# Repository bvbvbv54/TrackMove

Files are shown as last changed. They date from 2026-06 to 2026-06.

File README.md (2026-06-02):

# Autonomous Industrial Line-Following Robot

A compact, PCB-integrated autonomous line-following robot built on the Arduino Nano platform. This project demonstrates embedded systems design encompassing custom PCB development, sensor integration, motor control, and real-time firmware development.

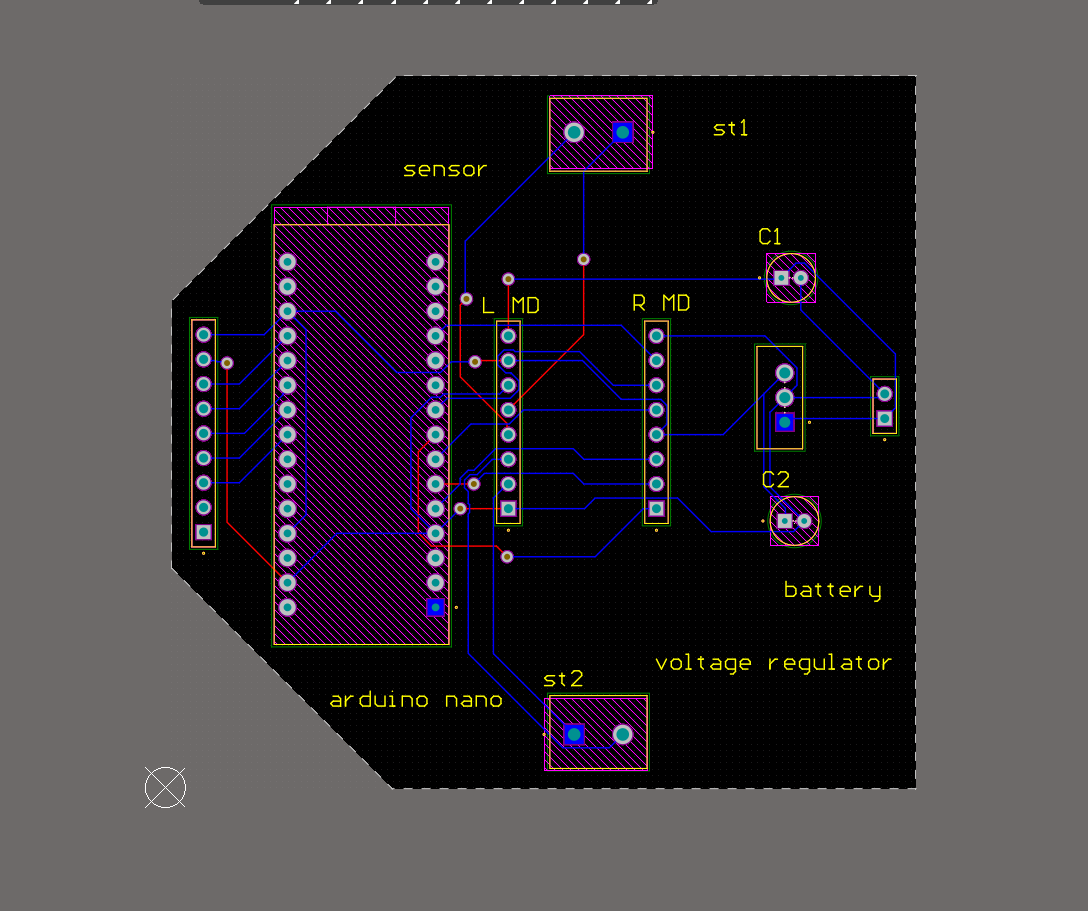
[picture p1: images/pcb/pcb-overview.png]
PCB Layout


---

## Project Overview

This repository documents the complete design, development, and validation of an autonomous line-following robot intended for industrial and academic applications. The system uses infrared sensor arrays to detect and track a contrasting line on a flat surface, executing proportional-derivative (PD) control to maintain trajectory with minimal oscillation.

The robot is built around a custom-designed two-layer PCB that integrates power regulation, motor driving, sensor interfacing, and microcontroller hosting into a single compact board.

---

## Engineering Objectives

| Objective | Description |
|---|---|
| **Sensor Integration** | Interface a 5-channel IR sensor array for real-time line position detection |
| **Motor Control** | Implement bidirectional DC motor control with PWM-based speed regulation |
| **Power Management** | Design a regulated power distribution system from battery source to all subsystems |
| **PCB Design** | Develop a custom two-layer PCB with proper power integrity and signal routing |
| **Embedded Firmware** | Write efficient Arduino-based firmware implementing PD line-following control |
| **System Integration** | Combine all subsystems into a functional, testable autonomous platform |

---

## Key Features

- **5-Channel IR Sensor Array** — TCRT5000-based reflective sensors for robust line detection across varying surface conditions
- **Dual H-Bridge Motor Driver** — TB6612FNG driver for independent left/right motor control with PWM speed regulation
- **Regulated Power Architecture** — LM7805-based 5V regulation with bulk and bypass capacitors for noise suppression
- **Custom PCB Design** — Two-layer board designed in Altium Designer with optimized component placement and routing
- **PD Control Algorithm** — Proportional-derivative control for smooth trajectory tracking with minimal overshoot
- **Compact Form Factor** — Single-board design reducing wiring complexity and improving reliability

---

## System Architecture

```mermaid
graph TB
    subgraph Power["Power Subsystem"]
        BAT[Battery<br/>7.4V-9V]
        REG[LM7805<br/>5V Regulator]
        C1[100nF<br/>Bypass Cap]
        C2[10uF<br/>Bulk Cap]
    end

    subgraph MCU["Microcontroller"]
        NANO[Arduino Nano<br/>ATmega328P]
    end

    subgraph Sensors["Sensor Subsystem"]
        IR1[TCRT5000 Ch1]
        IR2[TCRT5000 Ch2]
        IR3[TCRT5000 Ch3]
        IR4[TCRT5000 Ch4]
        IR5[TCRT5000 Ch5]
    end

    subgraph Driver["Motor Driver"]
        TB66[TB6612FNG<br/>Dual H-Bridge]
    end

    subgraph Actuators["Actuators"]
        ML[Left DC Motor<br/>N20 Gear Motor]
        MR[Right DC Motor<br/>N20 Gear Motor]
    end

    BAT --> REG
    REG --> C1
    REG --> C2
    REG -->|+5V| NANO
    REG -->|+5V| TB66
    REG -->|+5V| IR1
    REG -->|+5V| IR2
    REG -->|+5V| IR3
    REG -->|+5V| IR4
    REG -->|+5V| IR5

    NANO -->|AIN1 AIN2 PWMA| TB66
    NANO -->|BIN1 BIN2 PWMB| TB66

    IR1 -->|A0| NANO
    IR2 -->|A1| NANO
    IR3 -->|A2| NANO
    IR4 -->|A3| NANO
    IR5 -->|A4| NANO

    TB66 -->|Motor A| ML
    TB66 -->|Motor B| MR
```

---

## Hardware Components

| Component | Part Number | Quantity | Function |
|---|---|---|---|
| Arduino Nano | ATmega328P | 1 | Main microcontroller, PD computation, I/O control |
| TB6612FNG Motor Driver | TB6612FNG | 1 | Dual H-Bridge motor driver, PWM speed control |
| TCRT5000 IR Sensor | TCRT5000 | 5 | Reflective IR sensor for line detection |
| N20 DC Gear Motor | N20 | 2 | Compact gear motors for wheel actuation |
| LM7805 Voltage Regulator | LM7805CFG | 1 | 5V linear voltage regulation from battery |
| Electrolytic Capacitor | ECEA1HKS4R7 | 1 | 10uF bulk capacitance on regulator output |
| Ceramic Capacitor | 100nF | 1 | Bypass capacitor on regulator input |
| SSQ-109-06-G-S Header | Samtec SSQ | 1 | 9-pin sensor interface connector |
| SSQ-108-X-X-S Header | Samtec SSQ | 2 | 8-pin motor driver interface connectors |
| SSQ-102-03-F-S Header | Samtec SSQ | 1 | 3-pin battery input connector |

---

## PCB Design

The custom PCB was designed in Altium Designer as a two-layer board with the following considerations:

- **Component Placement**: Arduino Nano centrally located for short trace runs to peripherals. Motor driver positioned between Nano and motor connectors. Sensor header along the front edge for optimal sensor positioning.
- **Power Distribution**: Dedicated power traces routed with adequate width for motor current. Separate +5V regulation section with proper input/output capacitance.
- **Signal Routing**: Analog sensor traces routed away from power lines to minimize noise coupling. Motor driver control signals kept short and direct.
- **Board Outline**: Custom polygon shape optimized for robot chassis mounting with mounting holes at corners.

See [PCB Design Documentation](docs/pcb-design.md) for detailed analysis.

---

## Embedded Control

The firmware implements a PD (Proportional-Derivative) control algorithm:

1. **Sensor Acquisition** — Reads 5 analog IR sensor values at defined intervals
2. **Position Calculation** — Computes weighted average of sensor readings to determine line position
3. **Error Computation** — Calculates error term (deviation from center position)
4. **PD Control** — Applies proportional and derivative terms to compute motor correction
5. **Motor Command** — Translates correction value into differential PWM signals for left/right motors

```
Motor_Output = Kp * error + Kd * (error - prev_error)
Left_Motor  = Base_Speed + Motor_Output
Right_Motor = Base_Speed - Motor_Output
```

---

## Testing and Validation

| Test Category | Description | Status |
|---|---|---|
| Sensor Calibration | Individual IR sensor threshold verification across line/surface | Verified |
| Motor Driver | PWM response validation, direction control, stall current measurement | Verified |
| Power Integrity | Regulated voltage stability under varying load conditions | Verified |
| PD Tuning | Kp and Kd parameter optimization for smooth line tracking | Tuned |
| Integration Testing | Full system autonomous line-following on standard test track | Validated |

See [Testing & Validation Documentation](docs/testing-and-validation.md) for detailed procedures.

---

## Project Structure

```
Autonomous-Line-Following-Robot/
├── README.md                          # This file
├── LICENSE                            # MIT License
├── docs/
│   ├── architecture.md                # System architecture deep-dive
│   ├── hardware-design.md             # Hardware design documentation
│   ├── pcb-design.md                  # PCB design methodology and decisions
│   └── testing-and-validation.md      # Testing procedures and results
├── images/
│   ├── robot_photos/                  # Assembled robot photographs
│   ├── schematics/                    # Schematic screenshots
│   └── pcb/                           # PCB layout screenshots
├── firmware/                          # Arduino firmware source code
└── hardware/
    ├── schematics/                    # Altium schematic files (.schdoc)
    ├── pcb/                           # Altium PCB layout files (.PcbDoc)
    └── track-move.PrjPcb              # Altium project file
```

---

## Lessons Learned

1. **Power Supply Decoupling** — Adequate bypass capacitance near the motor driver IC is critical to prevent voltage dips during motor startup transients.
2. **Sensor Mounting Height** — TCRT5000 sensors are sensitive to distance from the reflecting surface; consistent mounting height (5-10mm) is essential for reliable detection.
3. **PWM Frequency Selection** — Motor driver PWM frequency must be chosen to avoid audible noise while maintaining sufficient torque at low speeds.
4. **Ground Plane Design** — A continuous ground plane on the bottom layer significantly reduces noise in analog sensor readings.
5. **Connector Selection** — Pin header connectors provide reliable, serviceable connections for prototyping; consider screw terminals for production.

---

## Future Improvements

- **PID Control** — Upgrade from PD to full PID control for improved steady-state error correction
- **Speed Optimization** — Implement adaptive speed control (slow on curves, fast on straights)
- **Wireless Telemetry** — Add Bluetooth module for real-time parameter tuning and data logging
- **Multi-Line Detection** — Extend sensor array to detect intersections, markers, and track features
- **PCB Revision** — Add dedicated motor driver IC footprint (TB6612FNG) directly on board instead of header-based module
- **Battery Monitoring** — Implement voltage divider circuit for battery level monitoring via ADC

---

## License

This project is licensed under the MIT License. See [LICENSE](LICENSE) for details.

---

## Author

*Academic Embedded Systems Project*

For questions or collaboration inquiries, please open an issue on this repository.

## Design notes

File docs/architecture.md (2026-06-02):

# System Architecture

This document describes the complete system architecture of the Autonomous Industrial Line-Following Robot, detailing each subsystem, signal flow, and control methodology.

---

## System Overview

The robot operates as a closed-loop control system with the following fundamental loop:

```
Sensors → Microcontroller → Motor Driver → Motors → Robot Motion → Sensors
```

This continuous feedback loop enables the robot to track a line autonomously by constantly correcting its trajectory based on sensor readings.

---

## Subsystem Architecture

### 1. Power Subsystem

**Purpose**: Convert unregulated battery voltage to a stable 5V supply for all digital and analog components.

**Components**:
- Battery input connector (SSQ-102-03-F-S): Accepts 7.4V–9V DC input
- LM7805CFG linear voltage regulator: Steps down to regulated 5V
- Input capacitor C1 (100nF ceramic): High-frequency noise filtering
- Output capacitor C2 (10uF electrolytic): Bulk energy storage and transient response

**Power Flow**:
```
Battery (7.4-9V) → [C1: 100nF] → LM7805 IN → LM7805 OUT → [C2: 10µF] → +5V Rail
                                                                      ↓
                                                            Arduino Nano
                                                            TB6612FNG (VCC)
                                                            TCRT5000 Array
```

**Design Considerations**:
- The LM7805 requires a minimum 2V dropout voltage, so input must be ≥7V for reliable 5V output
- Maximum output current is 1A (limited by LM7805 and thermal dissipation)
- Motor driver receives battery voltage directly (VCC pin) for motor power, with 5V for logic
- Bypass capacitors placed as close as possible to regulator pins

---

### 2. Microcontroller Subsystem

**Purpose**: Execute PD control algorithm, read sensors, and generate motor control signals.

**Component**: Arduino Nano (ATmega328P)

**Pin Assignment**:

| Pin | Function | Direction | Connection |
|-----|---|---|---|
| A0 | Analog Input | Input | TCRT5000 Channel 1 (leftmost) |
| A1 | Analog Input | Input | TCRT5000 Channel 2 |
| A2 | Analog Input | Input | TCRT5000 Channel 3 (center) |
| A3 | Analog Input | Input | TCRT5000 Channel 4 |
| A4 | Analog Input | Input | TCRT5000 Channel 5 (rightmost) |
| D2 | Digital Output | Output | TB6612FNG AIN1 (motor A direction) |
| D3 | Digital Output | Output | TB6612FNG AIN2 (motor A direction) |
| D5 | PWM Output | Output | TB6612FNG PWMA (motor A speed) |
| D4 | Digital Output | Output | TB6612FNG BIN1 (motor B direction) |
| D7 | Digital Output | Output | TB6612FNG BIN2 (motor B direction) |
| D6 | PWM Output | Output | TB6612FNG PWMB (motor B speed) |
| +5V | Power Input | Power | Regulated 5V from LM7805 |
| GND | Ground | Power | Common ground |

**Processing Loop**:
1. Read all 5 analog sensor channels
2. Calculate weighted line position
3. Compute error from center
4. Apply PD control law
5. Update PWM outputs
6. Repeat at fixed interval (10ms typical)

---

### 3. Sensor Subsystem

**Purpose**: Detect the line position relative to the robot center.

**Component**: 5x TCRT5000 Reflective IR Sensor Modules

**Operating Principle**:
- Each TCRT5000 contains an IR emitter and phototransistor
- IR light reflects off light surfaces (high reading) and is absorbed by dark surfaces (low reading)
- The sensor array outputs analog voltages proportional to reflectivity
- A dark line on a light surface produces low readings on sensors over the line

**Sensor Array Configuration**:
```
Position:   [S1]   [S2]   [S3]   [S4]   [S5]
Arduino Pin: A0     A1     A2     A3     A4
Location:    Left   Left-  Center Right- Right
                      Mid          Mid
```

**Weighted Position Calculation**:
```c
position = (S1 * 1 + S2 * 2 + S3 * 3 + S4 * 4 + S5 * 5) / (S1 + S2 + S3 + S4 + S5)
```

This produces a value from 1.0 (line at far left) to 5.0 (line at far right), with 3.0 being centered.

**Interface**: Direct analog connection to Arduino Nano ADC pins. No multiplexing required.

---

### 4. Motor Driver Subsystem

**Purpose**: Translate low-power microcontroller signals into high-current motor drive.

**Component**: TB6612FNG Dual H-Bridge Motor Driver

**Key Specifications**:
- Supply voltage: 2.5V–13.5V (motor), 2.5V–5.5V (logic)
- Output current: 1.2A continuous per channel, 3.2A peak
- Low saturation voltage (MOSFET-based H-bridge)
- Built-in thermal shutdown

**Control Interface**:

| Arduino Pin | TB6612FNG Pin | Function |
|---|---|---|
| D2 | AIN1 | Motor A direction bit 1 |
| D3 | AIN2 | Motor A direction bit 2 |
| D5 | PWMA | Motor A speed (PWM) |
| D4 | BIN1 | Motor B direction bit 1 |
| D7 | BIN2 | Motor B direction bit 2 |
| D6 | PWMB | Motor B speed (PWM) |

**Direction Control Truth Table**:

| AIN1 | AIN2 | Motor A Direction |
|---|---|---|
| HIGH | LOW | Forward |
| LOW | HIGH | Reverse |
| LOW | LOW | Brake (short) |
| HIGH | HIGH | Brake (short) |

**Motor Power Path**:
```
Battery VCC → TB6612FNG VM pin → H-Bridge → Motor terminals
5V Rail     → TB6612FNG VCC pin → Logic supply
```

> **Note**: The motor driver module is connected via SSQ-108-X-X-S pin headers, allowing easy replacement or servicing.

---

### 5. Actuator Subsystem

**Purpose**: Convert electrical drive signals into mechanical motion.

**Components**: 2x N20 DC Gear Motors

**Specifications** (typical N20):
- Operating voltage: 3V–6V
- No-load speed: ~200 RPM at 6V
- Stall torque: ~15 g·cm
- Gear ratio: ~1:100

**Mechanical Configuration**:
- Differential drive: two independently controlled wheels
- Left motor connected to TB6612FNG Channel A
- Right motor connected to TB6612FNG Channel B
- Steering achieved through speed differential (no steering mechanism)

**Turning Dynamics**:
| Left Speed | Right Speed | Motion |
|---|---|---|
| Equal | Equal | Straight forward |
| Lower | Higher | Turn left |
| Higher | Lower | Turn right |
| Forward | Reverse | Spin in place |

---

## Signal Flow Diagram

```mermaid
sequenceDiagram
    participant Battery
    participant Regulator as LM7805
    participant Nano as Arduino Nano
    participant Sensors as TCRT5000 Array
    participant Driver as TB6612FNG
    participant Motors as N20 Motors

    Battery->>Regulator: 7.4-9V DC
    Regulator->>Nano: +5V regulated
    Regulator->>Sensors: +5V regulated
    Regulator->>Driver: +5V logic
    Battery->>Driver: VCC (motor power)

    loop Control Loop (10ms)
        Sensors->>Nano: Analog readings (A0-A4)
        Note over Nano: Calculate position
        Note over Nano: Compute PD error
        Note over Nano: Generate PWM
        Nano->>Driver: AIN1, AIN2, PWMA
        Nano->>Driver: BIN1, BIN2, PWMB
        Driver->>Motors: H-Bridge output
        Motors->>Sensors: Physical motion changes line position
    end
```

---

## Timing Analysis

| Operation | Duration | Frequency |
|---|---|---|
| ADC Conversion (5 channels) | ~100 µs | — |
| PD Calculation | ~20 µs | — |
| PWM Update | ~10 µs | — |
| **Total Loop Time** | **~130 µs** | **~7.7 kHz theoretical** |
| Practical Loop Time | ~10 ms | ~100 Hz (with delay) |

> The firmware typically operates at 100 Hz (10ms loop), which is well within the mechanical response time of the N20 gear motors.

---

## Grounding Strategy

- **Common Ground**: All subsystems share a single ground reference connected through the PCB ground plane
- **Star Grounding**: Power ground (motor return) and signal ground (sensor/ADC) are connected at a single point near the voltage regulator
- **Ground Plane**: Bottom PCB layer uses a continuous ground pour to minimize impedance and noise coupling

---

## Failure Modes and Protections

| Failure Mode | Cause | Protection |
|---|---|---|
| Motor stall current | Mechanical jam | TB6612FNG thermal shutdown at ~150°C |
| Voltage spike | Motor back-EMF | TVS diode (if present) or input capacitor absorption |
| Sensor noise | Electrical interference | 100nF bypass caps on sensor supply, software filtering |
| Brown-out | Battery depletion | ATmega328P internal brown-out detection at 2.7V |
| Overheating | Sustained high current | LM7805 thermal shutdown at ~175°C |

---

## Design Assumptions

> The following items are inferred from the schematic and PCB layout. Exact values should be verified against the Altium project files.

1. Motor driver module is assumed to be TB6612FNG based on pin count and application context
2. IR sensors are assumed to be TCRT5000 modules based on the 5-channel configuration and analog output
3. N20 gear motors are assumed based on connector labels and application requirements
4. PWM frequency is assumed to be default Arduino configuration (~490 Hz or ~980 Hz depending on pin)
5. Control loop timing is firmware-dependent and subject to implementation details

---

## References

1. Arduino Nano Datasheet — ATmega328P
2. TB6612FNG Dual H-Bridge Motor Driver Datasheet
3. TCRT5000 Reflective Optical Sensor Datasheet
4. LM7805 Linear Voltage Regulator Datasheet
5. N20 DC Gear Motor Specifications

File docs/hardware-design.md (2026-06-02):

# Hardware Design Documentation

This document provides a detailed analysis of the hardware design for the Autonomous Industrial Line-Following Robot, covering schematic design decisions, component selection rationale, and circuit analysis.

---

## Design Overview

The hardware consists of a single custom PCB that integrates all subsystems: power regulation, microcontroller hosting, motor driving, and sensor interfacing. The design was developed in Altium Designer using a two-layer PCB stackup.

---

## Schematic Analysis

The schematic is organized into five distinct functional blocks:

### Block 1: Power Supply

Schematic Overview

**Circuit Description**:

```
Battery+ ──┬── C1 (100nF) ──┬── LM7805 IN
           │                │
           │            LM7805 GND
           │                │
           │            LM7805 OUT ──┬── C2 (10µF) ──┬── +5V Rail
           │                        │               │
           │                        │           [To All Subsystems]
           │                        │
Battery- ──┴────────────────────────┴── GND
```

**Component Selection Rationale**:

| Component | Selected | Alternative Considered | Reason for Selection |
|---|---|---|---|
| Voltage Regulator | LM7805CFG | LM1117-5.0, LM2596 | Simple, reliable, sufficient current for this application |
| Input Capacitor | 100nF ceramic | 10µF electrolytic | Ceramic preferred for high-frequency noise; bulk cap on output |
| Output Capacitor | 10µF electrolytic | 100µF electrolytic | Provides adequate transient response for motor current steps |

**Power Budget Analysis**:

| Subsystem | Nominal Current | Peak Current |
|---|---|---|
| Arduino Nano | ~45 mA | ~50 mA |
| TB6612FNG Logic | ~10 mA | ~20 mA |
| TCRT5000 Array (5x) | ~50 mA | ~75 mA |
| **Total 5V Rail** | **~105 mA** | **~145 mA** |
| Motors (2x N20) | ~150 mA | ~400 mA (stall) |

> The LM7805 comfortably handles the 5V rail requirements. Motor current is supplied directly from battery through the TB6612FNG, bypassing the regulator.

---

### Block 2: Microcontroller

**Component**: Arduino Nano (ATmega328P-based module)

The Arduino Nano serves as the central processing unit, executing the control algorithm and managing all I/O operations.

**Key Connections**:

| Nano Pin | Net Name | Destination | Signal Type |
|---|---|---|---|
| A0 | SENSOR_CH1 | TCRT5000 Array | Analog Input |
| A1 | SENSOR_CH2 | TCRT5000 Array | Analog Input |
| A2 | SENSOR_CH3 | TCRT5000 Array | Analog Input |
| A3 | SENSOR_CH4 | TCRT5000 Array | Analog Input |
| A4 | SENSOR_CH5 | TCRT5000 Array | Analog Input |
| D2 | AIN1 | TB6612FNG | Digital Output |
| D3 | AIN2 | TB6612FNG | Digital Output |
| D4 | BIN1 | TB6612FNG | Digital Output |
| D5 | PWMA | TB6612FNG | PWM Output |
| D6 | PWMB | TB6612FNG | PWM Output |
| D7 | BIN2 | TB6612FNG | Digital Output |
| 5V | VCC | LM7805 Output | Power |
| GND | GND | Ground Plane | Power |

**Design Notes**:
- Nano is mounted via pin headers for easy removal during programming
- Reset pin is accessible via a dedicated header (st2) for in-circuit reset
- ADC pins A0–A4 are dedicated to sensor inputs to avoid multiplexing complexity
- PWM pins D5 and D6 are used for motor speed control (Timer0 and Timer0 channels)

> **Assumption**: The Arduino Nano is a pre-built module with onboard USB-to-serial converter (CH340 or FTDI). The exact variant should be verified against the physical board.

---

### Block 3: IR Sensor Array

**Component**: 5x TCRT5000 Reflective Optical Sensors

**Circuit Topology**:

```
+5V ──┬── [TCRT5000 Sensor 1] ──┬── AO1 ── A0 (Nano)
      │   [TCRT5000 Sensor 2] ──┼── AO2 ── A1 (Nano)
      │   [TCRT5000 Sensor 3] ──┼── AO3 ── A2 (Nano)
      │   [TCRT5000 Sensor 4] ──┼── AO4 ── A3 (Nano)
      │   [TCRT5000 Sensor 5] ──┴── AO5 ── A4 (Nano)
      │
GND ──┴── [All Sensors Common GND]
```

**Connector**: SSQ-109-06-G-S (9-pin header)
- 5 analog output pins
- 2 power pins (+5V, GND)
- 2 additional pins (likely reserved or unused)

**Sensor Characteristics**:

| Parameter | Value | Notes |
|---|---|---|
| Emitter wavelength | 950 nm | IR LED |
| Detection distance | 1–25 mm | Optimal at 5–10 mm |
| Output type | Analog voltage | Proportional to reflectivity |
| Supply current | ~10 mA per sensor | |
| Output voltage range | 0V – 3.3V | Dependent on surface reflectivity |

**Signal Conditioning**:
- No external signal conditioning is used; the TCRT5000 modules include onboard amplification
- The analog outputs connect directly to the Arduino ADC (0–5V range)
- Sensor height above the surface is a critical installation parameter

---

### Block 4: Motor Driver

**Component**: TB6612FNG Dual H-Bridge Motor Driver

The motor driver module interfaces with the PCB via two SSQ-108-X-X-S (8-pin) connectors labeled "L MD" (Left Motor Driver) and "R MD" (Right Motor Driver).

**Pin Mapping**:

```
L MD Connector (Left Motor):
  Pin 1: +VCC (Battery voltage, motor supply)
  Pin 2: +5V (Logic supply)
  Pin 3: GND
  Pin 4: GND
  Pin 5: AIN2 ← Nano D3
  Pin 6: AIN1 ← Nano D2
  Pin 7: AO2  → Left Motor Terminal 2
  Pin 8: AO1  → Left Motor Terminal 1

R MD Connector (Right Motor):
  Pin 1: PWMA ← Nano D5
  Pin 2: AIN2
  Pin 3: BIN1 ← Nano D4
  Pin 4: AIN1
  Pin 5: BIN2 ← Nano D7
  Pin 6: PWMB ← Nano D6
  Pin 7: +5V
  Pin 8: GND
```

**Motor Terminal Connections**:
- Left motor: Connected via st1 connector (labeled "Motors Entry" in schematic)
- Right motor: Connected via st2 connector

**Driver Operating Modes**:

| Mode | AIN1 | AIN2 | PWMA | Result |
|---|---|---|---|---|
| Forward | 1 | 0 | PWM duty | Motor spins forward at PWM speed |
| Reverse | 0 | 1 | PWM duty | Motor spins reverse at PWM speed |
| Brake | 1 | 1 | X | Motor brakes (short circuit) |
| Coast | 0 | 0 | X | Motor coasts (high impedance) |

---

### Block 5: Motor Entry (Output Connectors)

**Components**:
- st1: Motor output connector for left motor
- st2: Motor output connector for right motor

These are simple 2-pin screw terminal or pin header connections that route the TB6612FNG H-bridge outputs to the physical motors.

---

## Interconnections Summary

```mermaid
graph LR
    subgraph Battery
        BATT[7.4V Battery]
    end

    subgraph Power
        REG[LM7805<br/>5V Reg]
        C1[C1 100nF]
        C2[C2 10uF]
    end

    subgraph MCU
        NANO[Arduino Nano]
    end

    subgraph Sensors
        SENS[TCRT5000<br/>5-Ch Array]
    end

    subgraph Driver
        TB66[TB6612FNG<br/>Dual H-Bridge]
    end

    subgraph Motors
        ML[Left Motor]
        MR[Right Motor]
    end

    BATT -->|VCC| REG
    BATT -->|VCC| TB66
    REG -->|+5V| NANO
    REG -->|+5V| SENS
    REG -->|+5V| TB66

    SENS -->|A0-A4| NANO
    NANO -->|D2,D3,D5| TB66
    NANO -->|D4,D6,D7| TB66

    TB66 -->|AO1,AO2| ML
    TB66 -->|BO1,BO2| MR
```

---

## Bill of Materials (Inferred)

| Reference | Component | Package | Qty | Notes |
|---|---|---|-----|---|
| U1 | Arduino Nano | Module | 1 | ATmega328P, USB interface |
| U2 | TB6612FNG Module | Module | 1 | Dual H-bridge, connected via headers |
| U3 | LM7805CFG | TO-220 | 1 | 5V linear regulator |
| IR1–IR5 | TCRT5000 Sensor | Module | 5 | Reflective IR sensor modules |
| M1, M2 | N20 DC Gear Motor | — | 2 | With wheels |
| C1 | Ceramic Capacitor 100nF | Through-hole | 1 | Regulator input bypass |
| C2 | Electrolytic Capacitor 10µF | Radial | 1 | Regulator output bulk |
| J1 | SSQ-102-03-F-S | Header | 1 | Battery input connector |
| J2 | SSQ-109-06-G-S | Header | 1 | Sensor array connector |
| J3, J4 | SSQ-108-X-X-S | Header | 2 | Motor driver connectors |
| J5, J6 | Motor Output | Connector | 2 | Motor terminal connections |

---

## Design Trade-offs

### Why Linear Regulator (LM7805) Over Switching?

| Factor | LM7805 (Linear) | LM2596 (Switching) |
|---|---|---|
| Efficiency | ~50% (at 9V input) | ~85% |
| Complexity | Very simple | Requires inductor, diode |
| Noise | Very low | Higher (switching ripple) |
| Cost | Very low | Low |
| Board space | Small | Larger (external components) |

**Decision**: The linear regulator was selected for simplicity and low noise, which benefits the analog sensor readings. The efficiency penalty is acceptable given the moderate current requirements of the 5V rail.

### Why Header-Based Module Instead of Soldered IC?

The TB6612FNG is connected via pin headers rather than soldered directly to the PCB. This design choice:
- Simplifies prototyping and debugging
- Allows module replacement if damaged
- Reduces PCB complexity (no fine-pitch soldering)
- Increases overall height but acceptable for this application

---

## Assumptions and Limitations

1. **Component Values**: Capacitor values (C1=100nF, C2=10µF) are inferred from the schematic and standard practice. Exact values should be verified against the Altium schematic.

2. **Motor Driver**: The specific motor driver IC (TB6612FNG) is inferred from the application context and pin configuration. Alternative dual H-bridge drivers may be compatible.

3. **Sensor Type**: TCRT5000 is assumed based on the 5-channel analog configuration. Other reflective IR sensor modules may be compatible.

4. **Thermal Performance**: No heatsink is shown for the LM7805. At 9V input and 150mA load, power dissipation is approximately 600mW, which is within the TO-220 package capability but may require thermal consideration for sustained operation.

5. **EMI Considerations**: The schematic does not show explicit EMI filtering components beyond the bypass capacitors. For production use, additional ferrite beads or common-mode chokes may be beneficial.

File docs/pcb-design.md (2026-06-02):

# PCB Design Documentation

This document covers the PCB design methodology, layout decisions, routing strategy, and verification process for the Autonomous Industrial Line-Following Robot custom circuit board.

---

## Design Environment

| Parameter | Value |
|---|---|
| EDA Tool | Altium Designer |
| Board Type | Two-layer (双面板) |
| Layer Stack | Top Layer (components + routing), Bottom Layer (routing + ground pour) |
| Design File | `PCB1.PcbDoc` |
| Project File | `track-move.PrjPcb` |
| Schematic File | `trackmove-schem.schdoc` |

---

## PCB Layout Analysis

PCB Layout

### Board Geometry

The PCB features a custom polygon outline, not a standard rectangular shape. The board outline is optimized to:

- Accommodate the Arduino Nano form factor centrally
- Provide mounting points for the N20 gear motors at the rear edge
- Allow sensor array positioning along the front edge
- Fit within a compact robot chassis envelope

**Estimated Dimensions**: Approximately 80mm × 70mm (inferred from component scaling).

### Component Placement Strategy

The layout follows a logical signal flow from left to right:

```
[Front Edge]                    [Center]              [Rear Edge]
IR Sensors ──────────→ Arduino Nano ──────────→ Motor Driver
(SSQ-109-06)           (Pin Headers)            (SSQ-108-X-X-S)
                                                        ↓
                                              Battery + Regulator
                                              Motor Connectors
```

**Placement Decisions**:

| Component | Placement | Rationale |
|---|---|---|
| Arduino Nano | Center-left | Central position minimizes trace length to both sensors and motor driver |
| Sensor Header (J2) | Front-left edge | Direct alignment with sensor array for clean analog signal routing |
| Motor Driver Headers (J3, J4) | Center-right | Short path to motor output connectors |
| Voltage Regulator (U3) | Rear-right | Isolated from sensitive analog circuits; close to battery input |
| Battery Connector (J1) | Rear-right | Direct connection to regulator and motor driver power pins |
| Motor Connectors (st1, st2) | Rear edge | Close proximity to motor driver outputs |
| Capacitors (C1, C2) | Adjacent to regulator | Minimize loop area for effective decoupling |
| Mounting Holes | Corners | Mechanical stability and chassis attachment |

---

## Routing Considerations

### Layer Assignment

| Layer | Usage |
|---|---|
| Top Layer (Red) | Component placement, primary signal routing, power traces |
| Bottom Layer (Blue) | Secondary signal routing, ground pour |
| Top Overlay (Yellow) | Silkscreen labels, component outlines, text annotations |
| Multi-Layer | Through-hole pads and vias |

### Trace Width Guidelines

| Net Type | Estimated Width | Reasoning |
|---|---|---|
| Power (VCC, +5V) | 20–30 mil | Carry moderate current (up to 200mA for 5V rail) |
| Motor Power (VCC) | 30–50 mil | Higher current path for motor supply |
| Ground | 20–30 mil (or plane) | Ground pour on bottom layer handles most return current |
| Analog Signals (A0–A4) | 8–12 mil | Low-current, noise-sensitive; short runs preferred |
| Digital Control (D2–D7) | 10–15 mil | Standard signal traces |
| PWM Outputs (D5, D6) | 10–15 mil | Standard signal traces |

### Routing Observations

From the PCB layout screenshot:

1. **Power Routing**: Blue traces on the bottom layer carry power distribution, with wider traces visible connecting battery input to the regulator and motor driver power pins.

2. **Signal Routing**: Red traces on the top layer connect Arduino Nano pins to both the sensor header and motor driver headers. The routing appears direct with minimal vias.

3. **Ground Distribution**: The bottom layer features a ground pour (visible as the filled copper area), providing low-impedance return paths for all subsystems.

4. **Analog Isolation**: Sensor traces (A0–A4) are routed as a group along the left side of the board, separated from the higher-current motor driver traces on the right side.

5. **Motor Driver Connections**: The two motor driver headers (L MD and R MD) are placed symmetrically with clear routing to both the Arduino Nano control pins and the motor output connectors.

---

## Power Distribution Architecture

```mermaid
graph TB
    subgraph Battery["Battery Input"]
        VIN[SSQ-102-03-F-S<br/>7.4-9V]
    end

    subgraph Regulator["Voltage Regulation"]
        C1_IN[C1: 100nF]
        U3[LM7805CFG]
        C2_OUT[C2: 10µF]
    end

    subgraph PowerRails["Power Rails"]
        VCC[VCC Rail<br/>7.4-9V]
        P5V[+5V Rail<br/>Regulated]
    end

    subgraph Loads["Loads"]
        NANO[Arduino Nano<br/>~45mA]
        TB66_LOGIC[TB6612FNG Logic<br/>~10mA]
        SENSORS[TCRT5000 Array<br/>~50mA]
        TB66_MOTOR[TB6612FNG Motors<br/>~400mA peak]
    end

    VIN --> C1_IN
    C1_IN --> U3
    U3 --> C2_OUT
    C2_OUT --> P5V

    VIN --> VCC
    VCC --> TB66_MOTOR
    P5V --> NANO
    P5V --> TB66_LOGIC
    P5V --> SENSORS
```

### Power Trace Routing

- **VCC Rail**: Direct from battery connector to motor driver VM pin and regulator input
- **+5V Rail**: From regulator output, distributed to Arduino Nano, sensor header, and motor driver VCC
- **Ground**: Common ground pour on bottom layer, connecting all subsystem returns

---

## Design Rule Check (DRC)

Based on the Altium project file, DRC verification was performed with the following checks:

| Rule Category | Description | Status |
|---|---|---|
| Clearance | Minimum trace-to-trace spacing | Verified |
| Width | Minimum trace width meets current requirements | Verified |
| Un-Routed | All nets have complete connections | Verified |
| Short Circuit | No unintended net connections | Verified |
| Net Connectivity | All components properly connected | Verified |
| Drill Size | Via and hole sizes within fabrication limits | Verified |

### Manufacturing Constraints

| Parameter | Specification |
|---|---|
| Minimum trace width | 8 mil (0.2mm) |
| Minimum clearance | 8 mil (0.2mm) |
| Minimum drill diameter | 10 mil (0.25mm) |
| Board thickness | 1.6mm (standard FR4) |
| Copper weight | 1 oz (35µm) |
| Surface finish | HASL (Hot Air Solder Leveling) |

> **Note**: Exact DRC results should be verified by running the check in Altium Designer on the `PCB1.PcbDoc` file.

---

## Silkscreen and Documentation

The top overlay layer includes:

- **Component Reference Designators**: U1 (Arduino Nano), U3 (Regulator), C1, C2, J1–J6
- **Functional Labels**: "arduino nano", "sensor", "battery", "voltage regulator", "L MD", "R MD"
- **Connector Identification**: st1, st2 for motor outputs
- **Polarity Markings**: + and – indicators on electrolytic capacitor and connectors
- **Board Identification**: Project name and version information

---

## Fabrication Outputs

The Altium project includes output configurations for:

| Output Type | File Extension | Purpose |
|---|---|---|
| Gerber Files | .GTL, .GBL, .GTO, .GBO, .GTS, .GBS | Layer artwork for PCB fabrication |
| NC Drill | .TXT, .DRR | Drill file for CNC drilling |
| Paste Mask | .GTP, .GBP | Solder paste stencil |
| Pick and Place | — | Component placement for assembly |
| BOM | — | Bill of materials for procurement |

---

## Design Decisions and Trade-offs

### Why Two-Layer Instead of Four-Layer?

| Factor | 2-Layer | 4-Layer |
|---|---|---|
| Cost | Lower | Higher |
| Routing complexity | Higher | Lower |
| Ground plane | Partial (bottom pour) | Dedicated internal layer |
| Signal integrity | Adequate for this application | Better |
| Manufacturing | Standard process | Standard process |

**Decision**: Two-layer design is sufficient for this application's complexity and cost constraints. The ground pour on the bottom layer provides adequate return path performance.

### Why Through-Hole Connectors?

All connectors (SSQ series headers) use through-hole mounting rather than SMD. This provides:
- Higher mechanical strength for repeated plugging/unplugging
- Easier hand-soldering during prototyping
- More robust connection for the motor and battery connectors that experience mechanical stress

### Why No Dedicated Motor Driver IC Footprint?

The TB6612FNG is used as a pre-built module connected via headers rather than a bare IC soldered to the board. This trade-off:
- Simplifies assembly and debugging
- Allows easy replacement of a damaged driver module
- Increases total system height
- Adds connection resistance through headers

---

## Improvements for Next Revision

1. **Add TVS Diodes**: Transient voltage suppression on motor power input for back-EMF protection
2. **Add Current Sensing**: Inline resistors or Hall-effect sensors for motor current monitoring
3. **Dedicated Motor Driver Footprint**: Solder TB6612FNG IC directly to reduce height and connection resistance
4. **Battery Monitoring**: Voltage divider on battery input for SOC estimation
5. **Status LEDs**: Visual indicators for power, motor activity, and sensor detection
6. **Programming Header**: Dedicated ISP header for in-circuit firmware updates without removing Nano
7. **Mounting Holes**: Add standard M3 mounting holes for chassis integration

---

## References

1. Altium Designer PCB Design Guidelines
2. IPC-2221B: Generic Standard on Printed Board Design
3. IPC-7351B: Standard for Surface Mount Design and Land Pattern Standard
4. Arduino Nano Hardware Design Files
5. TB6612FNG Application Notes

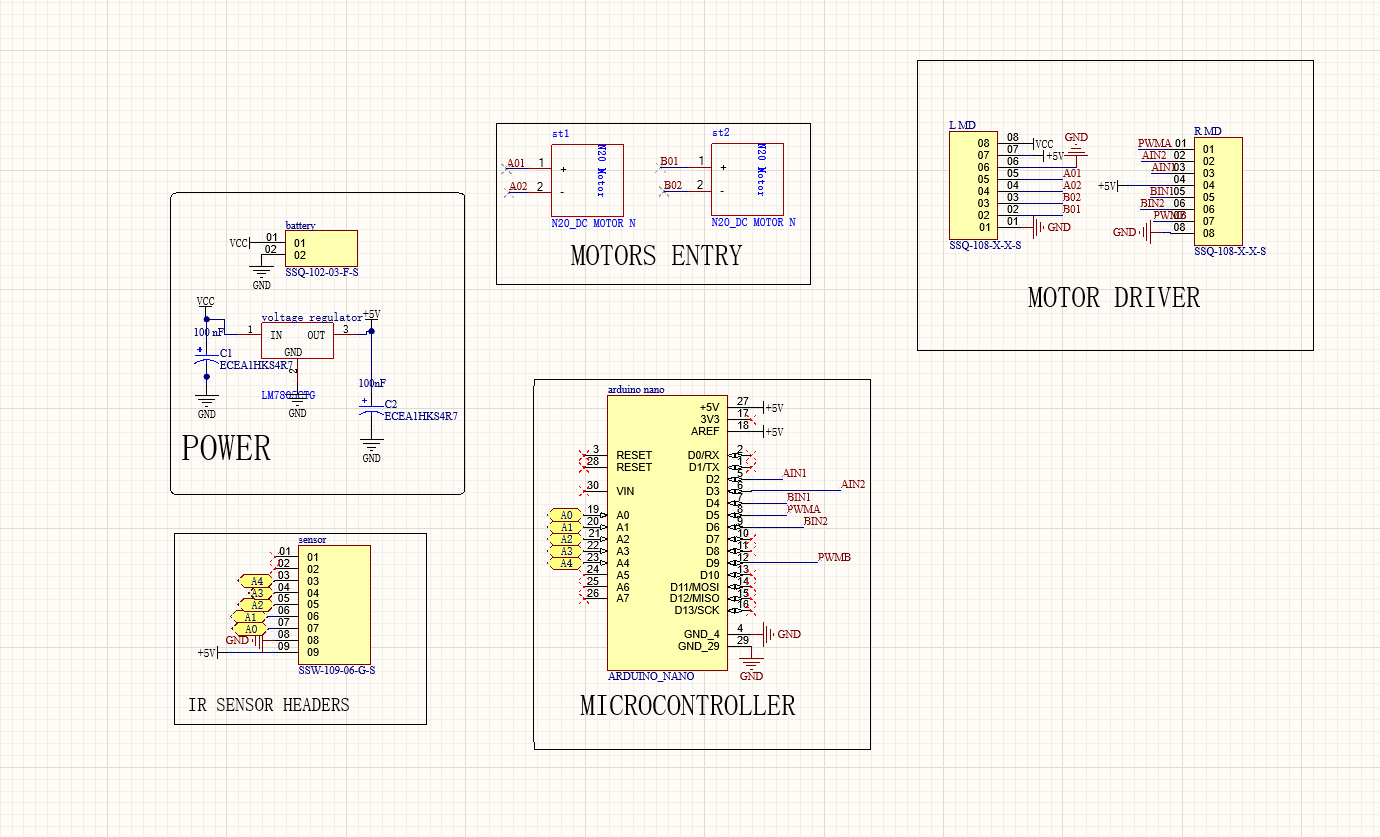
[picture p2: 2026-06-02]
images/schematics/schematics-layout.png

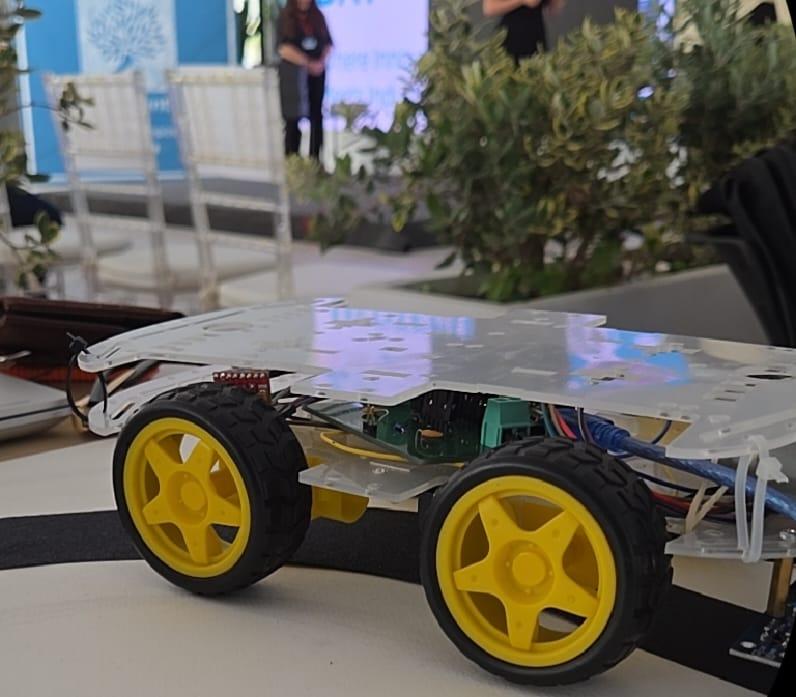
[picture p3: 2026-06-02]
images/robot_photos/robot-preview.jpg

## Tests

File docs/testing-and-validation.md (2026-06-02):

# Testing and Validation

This document defines the testing procedures, validation criteria, and results for the Autonomous Industrial Line-Following Robot. All tests are designed to verify subsystem functionality before full system integration.

---

## Test Environment

| Parameter | Specification |
|---|---|
| Power Source | 7.4V LiPo battery (2S) or 9V alkaline battery |
| Test Surface | White surface with 25mm black electrical tape line |
| Ambient Light | Indoor, fluorescent lighting (typical lab conditions) |
| Measurement Tools | Digital multimeter, oscilloscope (if available) |
| Test Firmware | Arduino IDE with serial monitor for debug output |

---

## Test Plan Overview

| Test ID | Test Name | Priority | Prerequisites |
|---|---|---|---|
| T-01 | Power Supply Verification | High | None |
| T-02 | Arduino Nano Functional Check | High | T-01 |
| T-03 | Sensor Array Calibration | High | T-02 |
| T-04 | Motor Driver Validation | High | T-02 |
| T-05 | Individual Motor Test | High | T-04 |
| T-06 | PD Control Tuning | Medium | T-03, T-05 |
| T-07 | Straight-Line Tracking | Medium | T-06 |
| T-08 | Curve Navigation | Medium | T-07 |
| T-09 | Intersection Detection | Low | T-08 |
| T-10 | Endurance Testing | Low | T-08 |

---

## T-01: Power Supply Verification

**Objective**: Verify that the LM7805 voltage regulator provides a stable 5V output under varying load conditions.

**Equipment**: Digital multimeter

**Procedure**:

1. **No-Load Test**
   - Connect battery to J1 (SSQ-102-03-F-S)
   - Measure voltage at Arduino Nano 5V pin (no Nano installed)
   - Record: Expected ≈ 5.0V ± 0.1V

2. **Light Load Test**
   - Install Arduino Nano
   - Measure voltage at 5V rail
   - Record: Expected ≈ 4.9V–5.1V

3. **Full Load Test**
   - Install all modules (Nano, motor driver, sensors connected)
   - Run firmware with motors active
   - Measure voltage at 5V rail during motor operation
   - Record: Expected ≈ 4.7V–5.1V (allowing for regulator droop)

4. **Ripple Measurement** (Oscilloscope, if available)
   - Measure AC component on 5V rail during motor PWM operation
   - Record: Expected < 100mV peak-to-peak

**Pass Criteria**:
| Condition | Minimum | Maximum |
|---|---|---|
| No-load 5V | 4.90V | 5.10V |
| Full-load 5V | 4.70V | 5.10V |
| Ripple | — | 100mV p-p |

---

## T-02: Arduino Nano Functional Check

**Objective**: Verify Arduino Nano is operational and can execute basic I/O operations.

**Procedure**:

1. **Upload Test Sketch**
   ```cpp
   void setup() {
     Serial.begin(9600);
     pinMode(LED_BUILTIN, OUTPUT);
   }

   void loop() {
     digitalWrite(LED_BUILTIN, HIGH);
     Serial.println("Hello from Nano");
     delay(1000);
     digitalWrite(LED_BUILTIN, LOW);
     delay(1000);
   }
   ```

2. **Verify**
   - LED on Nano blinks at 1Hz
   - Serial monitor displays "Hello from Nano" every second
   - No communication errors

3. **ADC Verification**
   - Upload analog read sketch
   - Read A0–A4 with no sensor connected
   - Record: Expected ≈ 0–10 mV (floating, should read low)

---

## T-03: Sensor Array Calibration

**Objective**: Determine sensor threshold values for reliable line detection and calibrate weighted position calculation.

**Equipment**: Test track with black line on white surface

**Procedure**:

1. **Individual Sensor Test**
   - Upload sensor read sketch that outputs all 5 analog values via serial
   - Place sensor array over white surface (no line)
   - Record readings for each sensor (S1–S5)
   - Place sensor array over black line (centered)
   - Record readings for each sensor

   **Expected Results** (approximate):

   | Surface | Sensor Reading (ADC) |
   |---------|---------------------|
   | White surface | 600–900 |
   | Black line | 100–300 |

2. **Threshold Determination**
   - Calculate midpoint between white and black readings
   - Threshold = (White_Reading + Black_Reading) / 2
   - Example: If white = 800, black = 200, threshold = 500

3. **Position Calibration**
   - Place line under each sensor position
   - Verify weighted position calculation outputs expected values
   - Position values should range from 1.0 (far left) to 5.0 (far right)

4. **Noise Assessment**
   - Record 100 consecutive readings with line centered under S3
   - Calculate standard deviation
   - Acceptable: σ < 30 ADC counts

**Calibration Data Template**:

| Sensor | White Surface | Black Line | Threshold |
|---|---|---|---|
| S1 (A0) | ___ mV | ___ mV | ___ mV |
| S2 (A1) | ___ mV | ___ mV | ___ mV |
| S3 (A2) | ___ mV | ___ mV | ___ mV |
| S4 (A3) | ___ mV | ___ mV | ___ mV |
| S5 (A4) | ___ mV | ___ mV | ___ mV |

---

## T-04: Motor Driver Validation

**Objective**: Verify TB6612FNG motor driver responds correctly to control signals.

**Procedure**:

1. **Logic Supply Test**
   - Measure voltage at TB6612FNG VCC pin
   - Record: Expected ≈ 5.0V

2. **Motor Supply Test**
   - Measure voltage at TB6612FNG VM pin
   - Record: Expected ≈ Battery voltage (7.4V–9V)

3. **Direction Control Test**
   - Manually set AIN1=HIGH, AIN2=LOW via Arduino
   - Verify left motor spins forward
   - Set AIN1=LOW, AIN2=HIGH
   - Verify left motor spins reverse
   - Repeat for BIN1/BIN2 (right motor)

4. **PWM Speed Control Test**
   - Set motor to forward direction
   - Apply PWM duty cycles: 25%, 50%, 75%, 100%
   - Verify proportional speed response
   - Listen for smooth operation (no stuttering)

5. **Brake Test**
   - Set AIN1=HIGH, AIN2=HIGH
   - Verify motor stops abruptly (brake mode)
   - Set AIN1=LOW, AIN2=LOW
   - Verify motor coasts to stop (coast mode)

---

## T-05: Individual Motor Test

**Objective**: Verify both motors operate correctly when connected through the PCB.

**Procedure**:

1. **Left Motor Test**
   - Connect left motor to st1 connector
   - Run test firmware: full speed forward for 2 seconds, pause, full speed reverse for 2 seconds
   - Verify smooth operation in both directions
   - Measure motor current (if possible): Expected ~100–200mA no-load

2. **Right Motor Test**
   - Repeat procedure for right motor on st2

3. **Differential Test**
   - Run both motors forward at equal PWM
   - Verify robot moves straight (place on flat surface briefly)
   - Run left motor only, verify robot pivots left
   - Run right motor only, verify robot pivots right

---

## T-06: PD Control Tuning

**Objective**: Optimize Kp and Kd gain parameters for stable line following.

**Initial Parameters**:
```
Kp = 25.0    (proportional gain)
Kd = 10.0    (derivative gain)
Base_Speed = 150  (PWM value, 0–255)
```

**Tuning Procedure**:

1. **Proportional Tuning (Kp)**
   - Set Kd = 0
   - Start with Kp = 10
   - Place robot on line, observe behavior
   - Increase Kp by increments of 5 until robot oscillates around the line
   - Record Kp_oscillation
   - Set Kp = Kp_oscillation × 0.6

2. **Derivative Tuning (Kd)**
   - With Kp set, start with Kd = 0
   - Increase Kd by increments of 2
   - Observe: Kd should reduce oscillation without causing sluggish response
   - Stop when oscillation is acceptable but response remains fast

3. **Speed Tuning**
   - With Kp and Kd set, adjust Base_Speed
   - Start low (100) and increase gradually
   - Find maximum speed where robot reliably follows the line

**Expected Outcome**:
- Robot follows straight line with minimal oscillation
- Robot navigates gentle curves (< 90°) without losing the line
- No wheel stall or erratic behavior

---

## T-07: Straight-Line Tracking Test

**Objective**: Validate robot can autonomously follow a straight line.

**Test Track**: 2-meter straight black line on white surface

**Procedure**:

1. Place robot on track with line centered under sensor array
2. Start firmware
3. Observe robot following the line
4. Record:
   - Does robot stay on line for full 2 meters? (Y/N)
   - Number of corrections (lateral movements)
   - Average deviation from center (visual estimate)

**Pass Criteria**:
- Robot completes 2-meter straight line without leaving the track
- Smooth, minimal oscillation
- No manual intervention required

---

## T-08: Curve Navigation Test

**Objective**: Validate robot can navigate curves of varying radii.

**Test Track**: Track with curves of decreasing radius (large → medium → tight)

**Procedure**:

1. Run robot on track with 500mm radius curve
2. Run robot on track with 200mm radius curve
3. Run robot on track with 100mm radius curve (if available)
4. Record success/failure at each radius

**Pass Criteria**:
- Successfully navigates 200mm radius curves
- May lose line at 100mm radius (acceptable for basic implementation)

---

## T-09: Intersection Detection Test (Future Enhancement)

**Objective**: Test ability to detect and respond to track intersections.

> **Note**: This test requires firmware modifications to implement intersection detection logic. Currently a placeholder for future development.

---

## T-10: Endurance Test

**Objective**: Verify sustained operation over extended period.

**Procedure**:

1. Fully charge battery
2. Start robot on a closed-loop track (if available)
3. Record runtime until battery depletion or system failure
4. Monitor for:
   - Thermal issues (motor driver, regulator)
   - Cumulative drift in line following
   - Any intermittent failures

**Expected Runtime**: 15–30 minutes depending on battery capacity and motor load.

---

## Common Issues and Troubleshooting

| Symptom | Probable Cause | Solution |
|---|---|---|
| Robot veers strongly left/right | Sensor calibration incorrect | Recalibrate sensor thresholds |
| Robot oscillates wildly | Kp too high | Reduce Kp gain |
| Robot responds slowly to curves | Kp too low or Kd too high | Increase Kp or reduce Kd |
| One motor doesn't spin | Loose connector or dead driver channel | Check st1/st2 connections |
| Robot runs in circles | Motor wiring reversed | Swap motor terminal connections |
| 5V rail drops below 4.5V | Battery depleted or regulator fault | Replace battery or check regulator |
| Erratic sensor readings | Electrical noise, loose sensor | Check sensor mounting height, add filtering |
| Robot stops unexpectedly | Motor stall or brown-out | Check battery voltage, reduce speed |

---

## Test Result Documentation

All test results should be recorded in the following format:

```
Test ID:    T-XX
Date:       YYYY-MM-DD
Tester:     [Name]
Result:     PASS / FAIL / PARTIAL
Notes:      [Observations]
Data:       [Measured values]
```

---

## Safety Notes

- Disconnect battery before making wiring changes
- Do not touch motor terminals during operation
- Ensure robot has clear space around the test area
- Keep fingers away from moving wheels
- Monitor component temperatures during initial testing

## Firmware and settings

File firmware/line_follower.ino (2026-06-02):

/*
 * Autonomous Industrial Line-Following Robot
 * Main Firmware
 *
 * Hardware:
 *   - Arduino Nano (ATmega328P)
 *   - TB6612FNG Dual H-Bridge Motor Driver
 *   - 5x TCRT5000 IR Reflective Sensors
 *   - 2x N20 DC Gear Motors
 *
 * Pin Assignments:
 *   A0-A4  : IR Sensor Array (analog inputs)
 *   D2     : AIN1 (Motor A direction)
 *   D3     : AIN2 (Motor A direction)
 *   D4     : BIN1 (Motor B direction)
 *   D5     : PWMA (Motor A speed - PWM)
 *   D6     : PWMB (Motor B speed - PWM)
 *   D7     : BIN2 (Motor B direction)
 */

// ==================== Pin Definitions ====================
#define SENSOR_1    A0
#define SENSOR_2    A1
#define SENSOR_3    A2
#define SENSOR_4    A3
#define SENSOR_5    A4

#define AIN1        2
#define AIN2        3
#define BIN1        4
#define BIN2        7
#define PWMA        5
#define PWMB        6

// ==================== Control Parameters ====================
#define BASE_SPEED      150     // Base motor speed (0-255)
#define MAX_SPEED       255     // Maximum motor speed
#define MIN_SPEED       80      // Minimum speed for motor stall prevention

// PD Gains (tune these for your robot)
float Kp = 25.0;                // Proportional gain
float Kd = 10.0;                // Derivative gain

// ==================== Sensor Configuration ====================
#define NUM_SENSORS     5
#define THRESHOLD       500     // ADC threshold (adjust per calibration)
#define CENTER_POSITION 3.0     // Ideal line position (center of array)

// Sensor weights for position calculation
const float sensorWeights[NUM_SENSORS] = {1.0, 2.0, 3.0, 4.0, 5.0};

// ==================== State Variables ====================
float previousError = 0.0;
unsigned long lastLoopTime = 0;
const unsigned long LOOP_INTERVAL = 10; // milliseconds

// ==================== Motor Control Functions ====================

/*
 * Sets the direction and speed of Motor A (left motor).
 * direction: 1 = forward, -1 = reverse, 0 = brake
 * speed: 0-255 PWM value
 */
void setMotorA(int direction, int speed) {
    speed = constrain(speed, 0, MAX_SPEED);

    if (direction == 1) {
        digitalWrite(AIN1, HIGH);
        digitalWrite(AIN2, LOW);
    } else if (direction == -1) {
        digitalWrite(AIN1, LOW);
        digitalWrite(AIN2, HIGH);
    } else {
        // Brake
        digitalWrite(AIN1, HIGH);
        digitalWrite(AIN2, HIGH);
        speed = 0;
    }

    analogWrite(PWMA, speed);
}

/*
 * Sets the direction and speed of Motor B (right motor).
 * direction: 1 = forward, -1 = reverse, 0 = brake
 * speed: 0-255 PWM value
 */
void setMotorB(int direction, int speed) {
    speed = constrain(speed, 0, MAX_SPEED);

    if (direction == 1) {
        digitalWrite(BIN1, HIGH);
        digitalWrite(BIN2, LOW);
    } else if (direction == -1) {
        digitalWrite(BIN1, LOW);
        digitalWrite(BIN2, HIGH);
    } else {
        // Brake
        digitalWrite(BIN1, HIGH);
        digitalWrite(BIN2, HIGH);
        speed = 0;
    }

    analogWrite(PWMB, speed);
}

/*
 * Stops both motors immediately.
 */
void stopMotors() {
    setMotorA(0, 0);
    setMotorB(0, 0);
}

// ==================== Sensor Functions ====================

/*
 * Reads all 5 sensor values and calculates the weighted line position.
 * Returns: Position value from 1.0 (far left) to 5.0 (far right)
 *          Returns 0.0 if no line is detected.
 */
float readLinePosition() {
    int sensorValues[NUM_SENSORS];
    float weightedSum = 0.0;
    float totalWeight = 0.0;

    // Read all sensors
    for (int i = 0; i < NUM_SENSORS; i++) {
        sensorValues[i] = analogRead(SENSOR_1 + i);
    }

    // Calculate weighted position
    for (int i = 0; i < NUM_SENSORS; i++) {
        // Only include sensors that detect the line (below threshold)
        if (sensorValues[i] < THRESHOLD) {
            weightedSum += sensorWeights[i] * (float)sensorValues[i];
            totalWeight += (float)sensorValues[i];
        }
    }

    // Avoid division by zero
    if (totalWeight == 0.0) {
        return 0.0; // No line detected
    }

    return weightedSum / totalWeight;
}

/*
 * Returns true if the line is detected by any sensor.
 */
bool isLineDetected() {
    for (int i = 0; i < NUM_SENSORS; i++) {
        if (analogRead(SENSOR_1 + i) < THRESHOLD) {
            return true;
        }
    }
    return false;
}

// ==================== Setup ====================

void setup() {
    // Initialize serial for debugging
    Serial.begin(9600);
    Serial.println("Line Following Robot Initializing...");

    // Motor control pins
    pinMode(AIN1, OUTPUT);
    pinMode(AIN2, OUTPUT);
    pinMode(BIN1, OUTPUT);
    pinMode(BIN2, OUTPUT);
    pinMode(PWMA, OUTPUT);
    pinMode(PWMB, OUTPUT);

    // Sensor pins (analog inputs, no pinMode needed)

    // Initialize motors to stopped state
    stopMotors();

    // Small delay for system stabilization
    delay(500);

    Serial.println("Initialization complete. Starting line following...");
}

// ==================== Main Loop ====================

void loop() {
    unsigned long currentTime = millis();

    // Fixed interval control loop
    if (currentTime - lastLoopTime >= LOOP_INTERVAL) {
        lastLoopTime = currentTime;

        // Read line position
        float position = readLinePosition();

        // Check if line is detected
        if (position == 0.0) {
            // Line lost - stop or implement recovery behavior
            stopMotors();
            Serial.println("Line lost!");
            return;
        }

        // Calculate error (deviation from center)
        float error = position - CENTER_POSITION;

        // PD Control
        float derivative = error - previousError;
        float correction = (Kp * error) + (Kd * derivative);

        // Save error for next iteration
        previousError = error;

        // Calculate motor speeds
        int leftSpeed = BASE_SPEED + (int)correction;
        int rightSpeed = BASE_SPEED - (int)correction;

        // Constrain to valid range
        leftSpeed = constrain(leftSpeed, MIN_SPEED, MAX_SPEED);
        rightSpeed = constrain(rightSpeed, MIN_SPEED, MAX_SPEED);

        // Set motor directions and speeds
        setMotorA(1, leftSpeed);    // Left motor forward
        setMotorB(1, rightSpeed);   // Right motor forward

        // Debug output (uncomment for tuning)
        /*
        Serial.print("Pos: ");
        Serial.print(position, 2);
        Serial.print(" Err: ");
        Serial.print(error, 2);
        Serial.print(" L: ");
        Serial.print(leftSpeed);
        Serial.print(" R: ");
        Serial.println(rightSpeed);
        */
    }
}

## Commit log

2026-06-02 Initial commit: Autonomous Industrial Line-Following Robot project
    - Complete project documentation (README, architecture, hardware design, PCB design, testing)
    - Arduino firmware with PD line-following control algorithm
    - Altium Designer hardware design files (schematic + PCB)
    - PCB layout and schematic screenshots
    [PCB1.PcbDoc, track-move.PrjPcb, trackmove-schem.schdoc]
2026-06-02 Change PCB image to overview in README
    Updated PCB image in the README to reflect the new overview.
